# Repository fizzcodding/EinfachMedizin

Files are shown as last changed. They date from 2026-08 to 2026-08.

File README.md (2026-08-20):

# EinfachMedizin

Autonomous medicine dispensing module. This repo covers the mechanical build only: CAD files, design decisions, and assembly. No firmware, no software.

The machine holds up to 21 doses on a rotating carousel disc, indexes to the correct slot using a stepper motor and absolute encoder, and releases the dose through a servo-actuated gate into a collection drawer at the bottom. Dispense only happens after 3-way verification clears — that system isn't documented here.

The problem it's built to solve is medication adherence. Specifically, patients who need the right pill at the right time and can't always rely on a caregiver being physically present to hand it to them.
---
## BOM
This is the Bill of Materials (BOM) for the project.
#### ngl the prices in amazon is high, these are so cheap in my countries D:
- stepper motor - NEMA17HS3401 - 1 piece = 42 USD - https://www.amazon.com/17HS3401-4-Lead-Stepper-Motor-42BYGH/dp/B0DKBV65SR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 
- Servo motor - TowerPro MG996R 180° - 2 piece = 9.99 USD - https://www.amazon.com/AEDIKO-MG996R-Control-Digital-Helicopter/dp/B09BZ5955Z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
- stepper driver - TMC2209 - 1 piece = 11 USD - https://www.amazon.com/TMC2209-Stepper-Continuous-Microstepping-Heatsink/dp/B0H6XVZR7Q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
- magnetic encoder - AS5600 - 1 piece = 6 USD - www.amazon.com/Magnetic-Encoder-Induction-Measurement-Precision/dp/B0GWWND79S?crid=10GXJ9I8UYX2V&dib=eyJ2IjoiMSJ9.sRkyQzCSLKrouEOa6e23GlldUhq7O8OW-pzImgFcGQcYi-3cP-rZLooNAZZhX93R-zH7nipYZ57iWoBm4-vS5dq8ARd9JFuVg5kdCizsGIStXFZo94Jmp27rA94WvTwAFOi4UVA2d6OzW-4mXF_CawcUCN73aMngRcCiI_M0cQYFNmXOzkwnRgHqHmfH2KCXZHmdaGWhuDXCnjbIurk7eHiSY9ximhOgFq8R-EimiBI.oWKwHE8aNsdnJryt8nzT2Q_5y3R_CQ3v39gIENoHxD0&dib_tag=se&keywords=as5600+magnetic+encoder&qid=1787200709&sprefix=as5600+magnetic+enco%2Caps%2C358&sr=8-14
- 3d printing - 30 USD??? Not sure how much this is, but it's definitely not free.

---

## Stack

Four layers, top to bottom:

```
[ Carousel      ]  ← holds the pills
[ Gate          ]  ← controls release
[ Funnel        ]  ← guides pill downward
[ Drawer        ]  ← collection point
```

All four layers are friction-fit. No fasteners, no adhesive between them. Everything is PLA.

CAD is in Onshape.

---

## Carousel

6.500" OD disc with 21 compartment slots arranged around the circumference. Slots are evenly spaced — 360° / 21 ≈ 17.14° per step. No dedicated index/reference slot; absolute position comes from the encoder, not a mechanical marker.

The slot walls use a full-round fillet all the way around the opening. The reason is simple: any sharp corner or chamfer is a snag point for capsules. A full round lets the pill slide out clean when the gate opens. It costs nothing in print time and eliminates a whole failure mode.

The carousel sits on a central shaft driven directly by a NEMA17 stepper. No belt, no gearing. Direct drive keeps the mechanism tight, removes backlash, and means the encoder reading maps cleanly to actual disc position without having to compensate for drivetrain slop.

Two drive-system features shown in the reference render are not yet implemented: outer rim gear teeth around the disc circumference, and a horizontal drive shaft arrangement to replace the current center-shaft drive. Both are planned for an upcoming revision.

---

## Gate Mechanism

Pinion-rack, servo-actuated. When a dispense is triggered, the servo drives a rack that slides the gate open *horizontally* — a linear push, not a flap or trap-door. The slot opening is exposed, the dose drops through, gate closes.

The linear slide was chosen over a rotary flap because it's more predictable: defined open/closed positions, no gravity fighting the mechanism at odd angles, and the travel distance is easy to constrain mechanically.

---

## Funnel

Tapered channel that sits below the gate and guides the released pill down to the drawer.

---

## Drawer

Collection tray at the bottom. Friction-fits onto the funnel. Patient pulls it out to get the dose.

---

## Position Tracking

Position is tracked with an AS5600 magnetic absolute encoder. The diametrically magnetized magnet mounts on a shaft extending from the underside of the carousel disc.

The reason for using an absolute encoder over incremental (hall-effect pulse counting, basic optical encoder, etc.): incremental encoders lose position on power loss. For a dispenser, getting the wrong slot after a power cycle isn't just inconvenient — it's a real failure mode. The AS5600 gives absolute position on every power-up with no homing routine needed, and the cost delta over an incremental solution is negligible.

---

## Assembly

Stack in order: carousel on top, then gate layer, funnel, drawer at the bottom. Push each layer together — friction-fit holds them.

The NEMA17 mounts below the carousel layer and drives the central shaft from underneath. The AS5600 encoder sits on a shaft extending from the underside of the carousel disc.

# Medicine Dispenser Wiring

## ESP32 → TMC2209

| ESP32 | TMC2209 |
|---|---|
| STEP GPIO | STEP |
| DIR GPIO | DIR |
| ENABLE GPIO | EN/ENN |
| UART TX/RX | PDN_UART |
| 3.3V | VIO |
| GND | GND |

## TMC2209 → NEMA17 17HS3401

| TMC2209 | NEMA17 |
|---|---|
| OA1 | Coil A |
| OA2 | Coil A |
| OB1 | Coil B |
| OB2 | Coil B |

## ESP32 → AS5600

| ESP32 | AS5600 |
|---|---|
| 3.3V | VCC |
| GND | GND |
| SDA GPIO | SDA |
| SCL GPIO | SCL |

## ESP32 → MG995 #1 — Shutter

| Connection | MG995 #1 |
|---|---|
| Servo GPIO | SIGNAL |
| Servo Power | V+ |
| Common GND | GND |

## ESP32 → MG995 #2 — Slider Crank

| Connection | MG995 #2 |
|---|---|
| Servo GPIO | SIGNAL |
| Servo Power | V+ |
| Common GND | GND |

## Power

| Source | Destination |
|---|---|
| USB-C Power Bank | Main Power Input |
| Main Power | ESP32 |
| Main Power | TMC2209 Motor Power |
| Main Power | Servo Power Rail |
| Servo Power Rail | MG995 #1 V+ |
| Servo Power Rail | MG995 #2 V+ |
| Common GND | ESP32 GND |
| Common GND | TMC2209 GND |
| Common GND | AS5600 GND |
| Common GND | MG995 #1 GND |
| Common GND | MG995 #2 GND |

## AS5600 Physical Placement

| Component | Position |
|---|---|
| Carousel Magnet | Directly above AS5600 |
| AS5600 | Centered underneath magnet |
| AS5600 PCB | Fixed beneath carousel |

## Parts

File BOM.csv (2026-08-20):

Component | Part Number | Quantity | Unit Price (USD) | Total Price (USD) | Purchase Link
Stepper Motor | NEMA17HS3401 | 1 | 42.00 | 42.00 | https://www.amazon.com/17HS3401-4-Lead-Stepper-Motor-42BYGH/dp/B0DKBV65SR
Servo Motor | TowerPro MG996R 180° | 2 | 9.99 | 19.98 | https://www.amazon.com/AEDIKO-MG996R-Control-Digital-Helicopter/dp/B09BZ5955Z
Stepper Driver | TMC2209 | 1 | 11.00 | 11.00 | https://www.amazon.com/TMC2209-Stepper-Continuous-Microstepping-Heatsink/dp/B0H6XVZR7Q
Magnetic Encoder | AS5600 | 1 | 6.00 | 6.00 | https://www.amazon.com/Magnetic-Encoder-Induction-Measurement-Precision/dp/B0GWWND79S
3D Printing | PLA Parts |  |  | 30.00

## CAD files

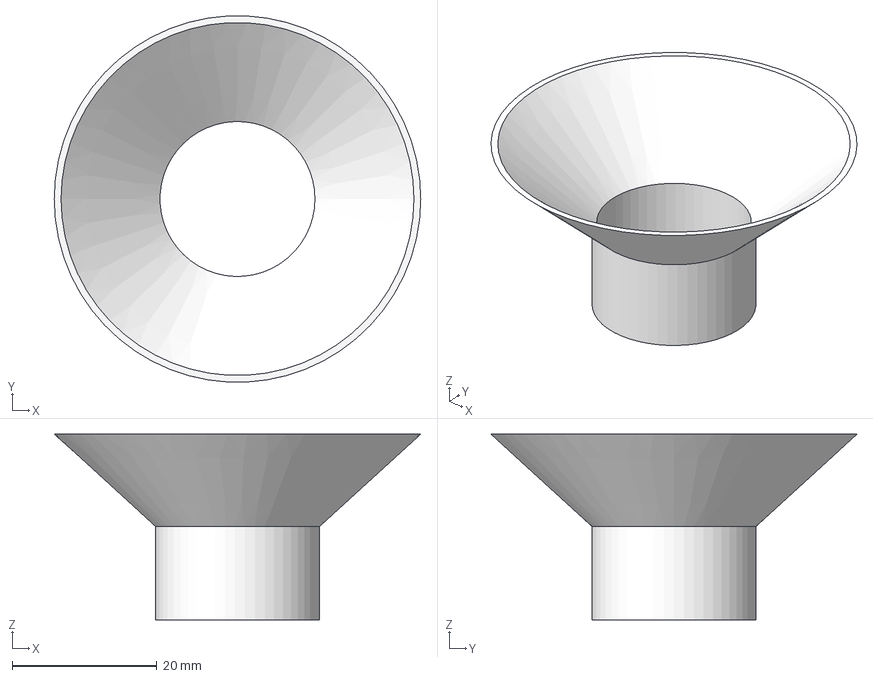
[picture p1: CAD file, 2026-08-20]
Funnel for Medicine Drop.step
50.7 x 50.6 x 25.7 mm

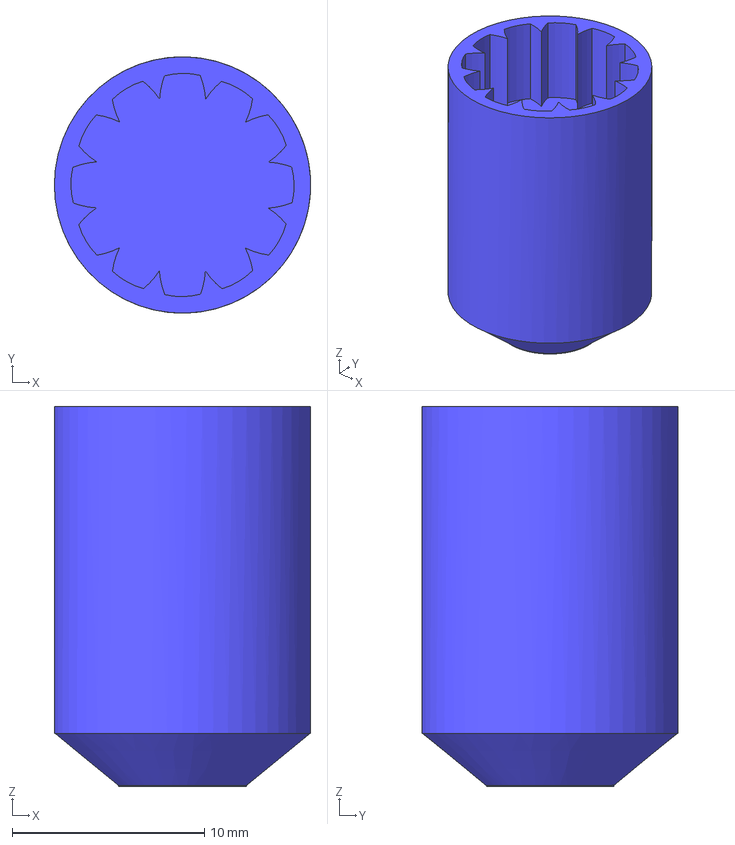
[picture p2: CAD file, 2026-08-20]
Connecter Between MG996R and Contrl Disc.step
13.3 x 13.3 x 19.7 mm

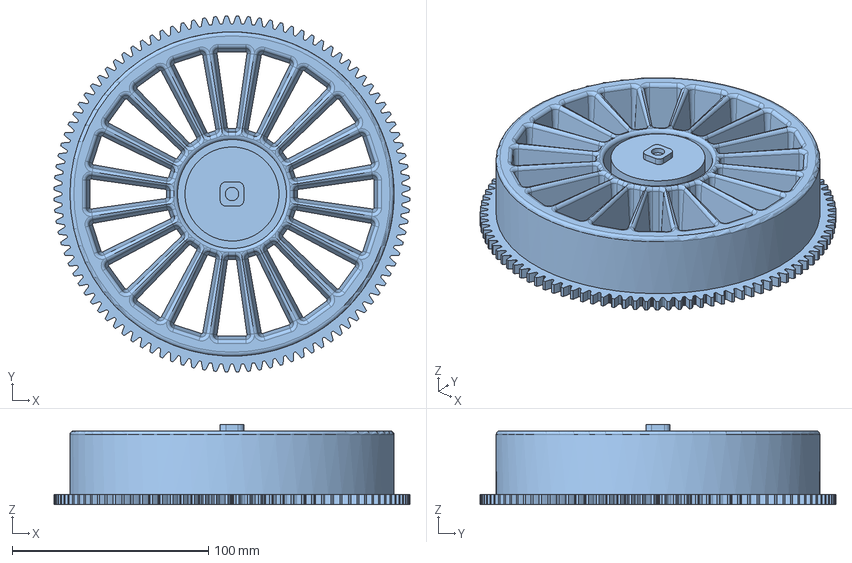
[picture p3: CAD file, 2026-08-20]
CarouselDisc(1).step
181.3 x 181.3 x 40.8 mm

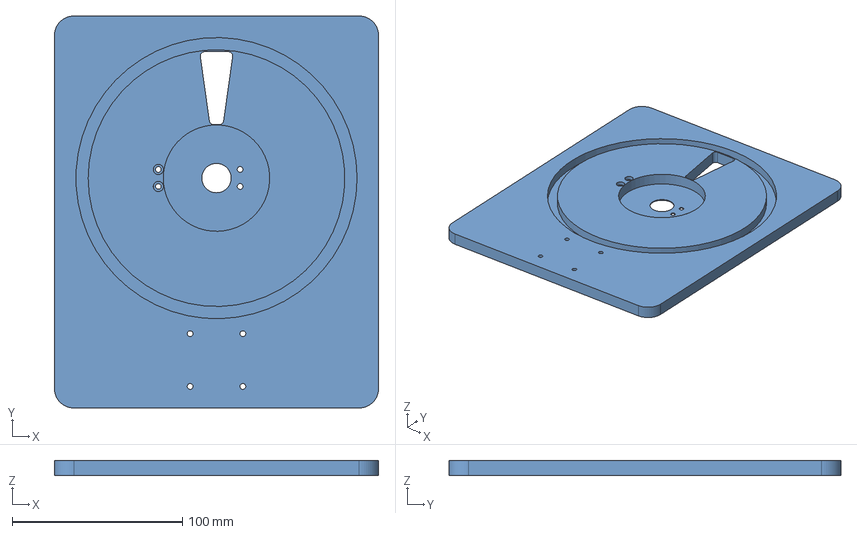
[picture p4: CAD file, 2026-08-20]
Structural Layer - Fixed Layer.step
190.5 x 230.3 x 8.59 mm

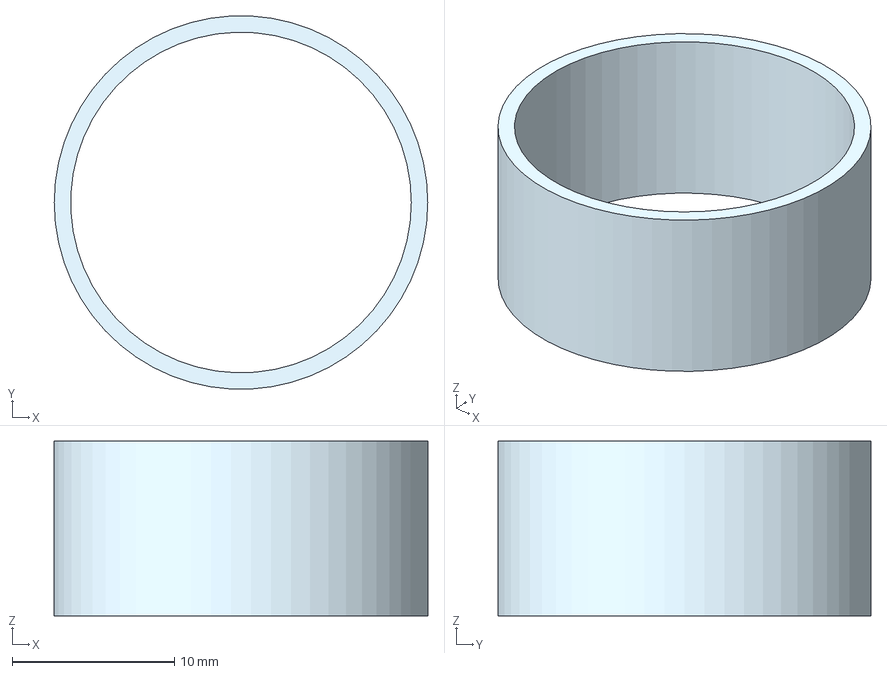
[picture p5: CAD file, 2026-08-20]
Funnel Drop In.step
23.1 x 23.0 x 10.8 mm

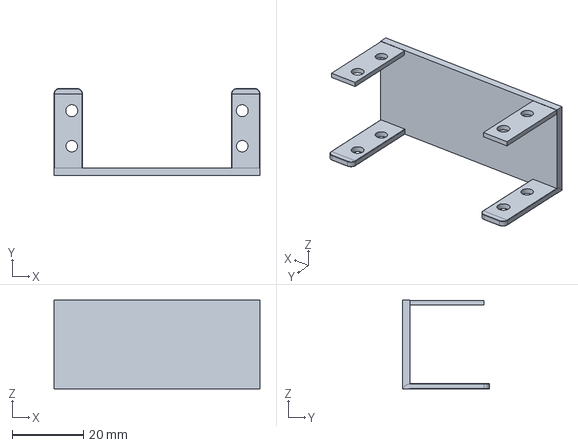
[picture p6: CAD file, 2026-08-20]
Mountable Bracket for MG996R.step
58.0 x 24.5 x 25.0 mm

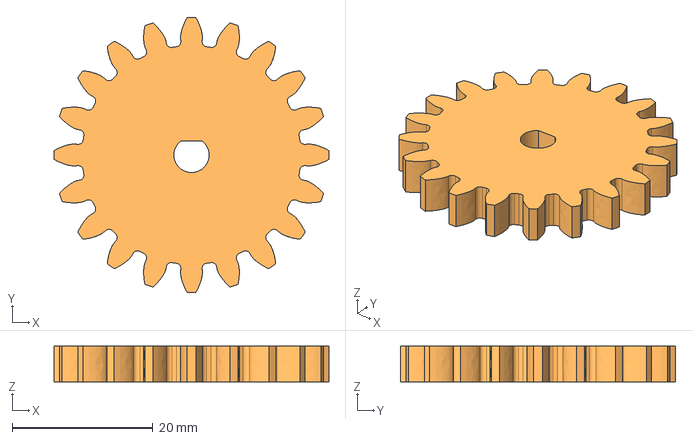
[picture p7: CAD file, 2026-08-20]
PinionGear(1).step
39.1 x 39.1 x 5.08 mm

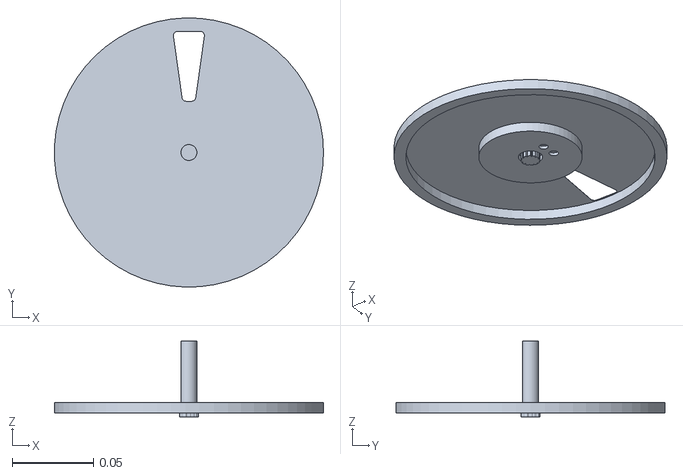
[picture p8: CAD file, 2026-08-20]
Shutter Disc.stl
0.165 x 0.165 x 0.0466

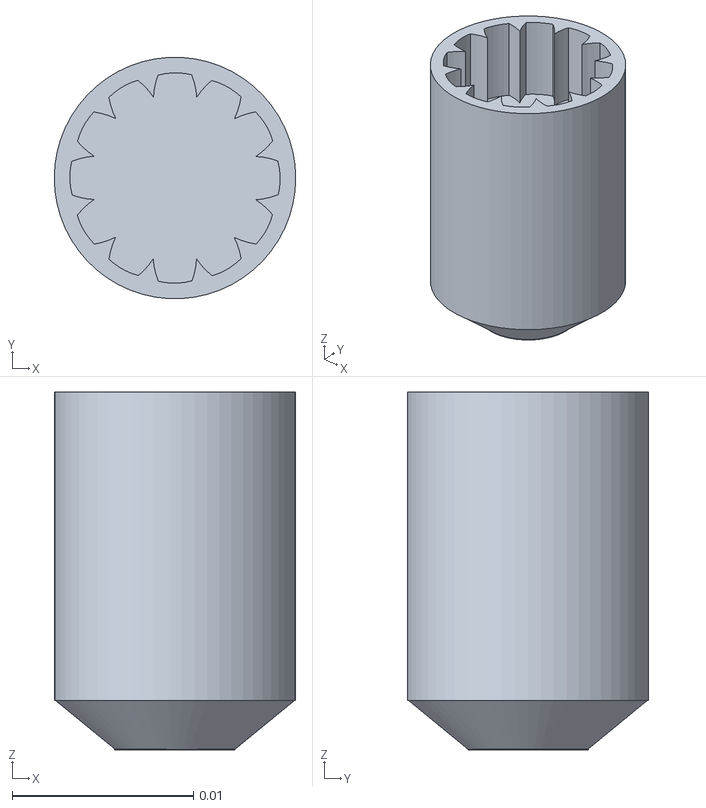
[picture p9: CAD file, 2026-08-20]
Connecter Between MG996R and Shutter Dissc.stl
0.0133 x 0.0133 x 0.0197

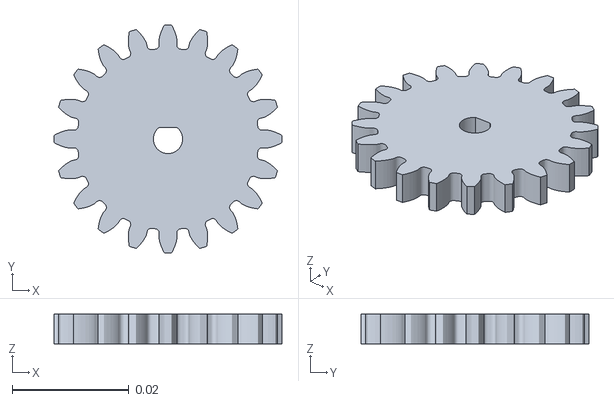
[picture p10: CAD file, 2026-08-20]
PinionGear(2).stl
0.0391 x 0.0391 x 0.00508

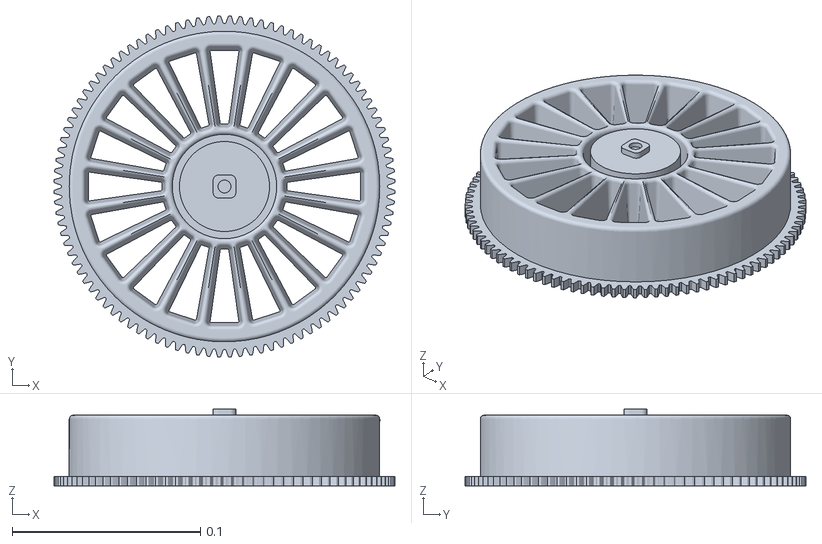
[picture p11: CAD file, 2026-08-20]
Center Shaft + Final Discs - CarouselDisc.stl
0.181 x 0.181 x 0.0408

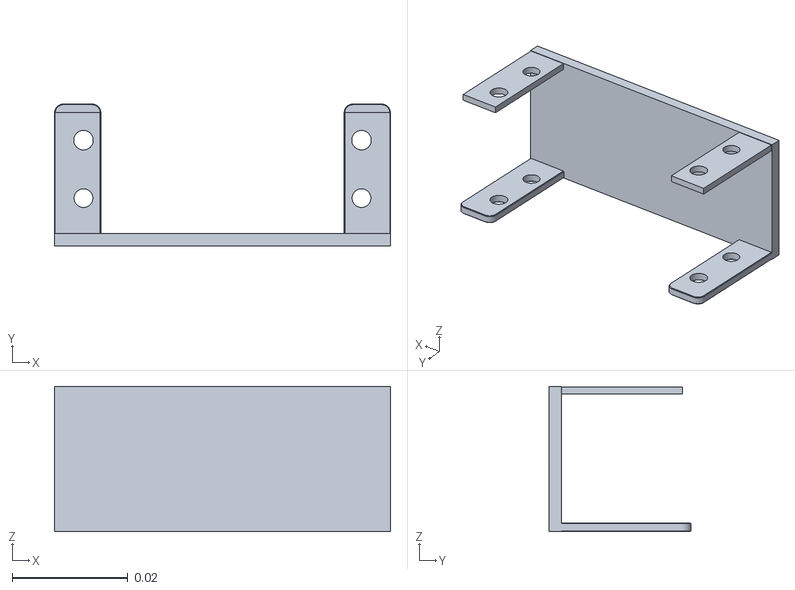
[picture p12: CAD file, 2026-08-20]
Bracket for Servo to be mounted on structural layer.stl
0.058 x 0.0245 x 0.025

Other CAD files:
Funnel Drop In.stl
Funnel For Medicine Drop.stl
Structural Layer - Fixed Layer.stl

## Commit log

2026-08-07 hackclub commit
    [Carousel Disc.step, Control Disc.step, Fixed Plate.step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]
2026-08-20 crazy changes
    [Bracket for Servo to be mounted on structural layer.stl, Carousel Disc.step, Center Shaft + Final Discs - CarouselDisc.stl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]
2026-08-20 step files
    [CarouselDisc(1).step, Connecter Between MG996R and Contrl Disc.step, Funnel Drop In.step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]
